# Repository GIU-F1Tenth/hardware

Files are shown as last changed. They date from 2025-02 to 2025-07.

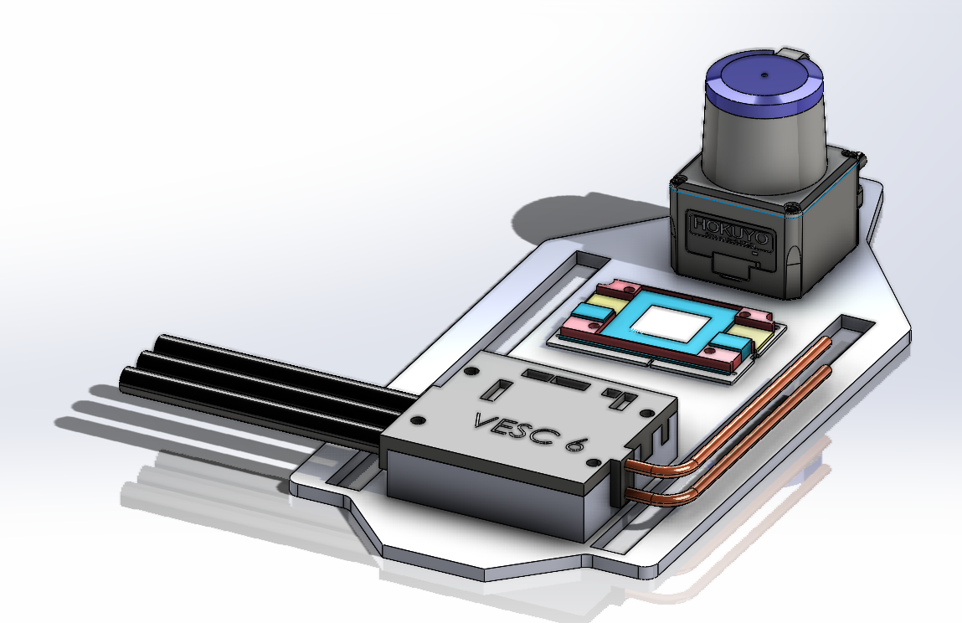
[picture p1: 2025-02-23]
Components3DModelling/Assm.png

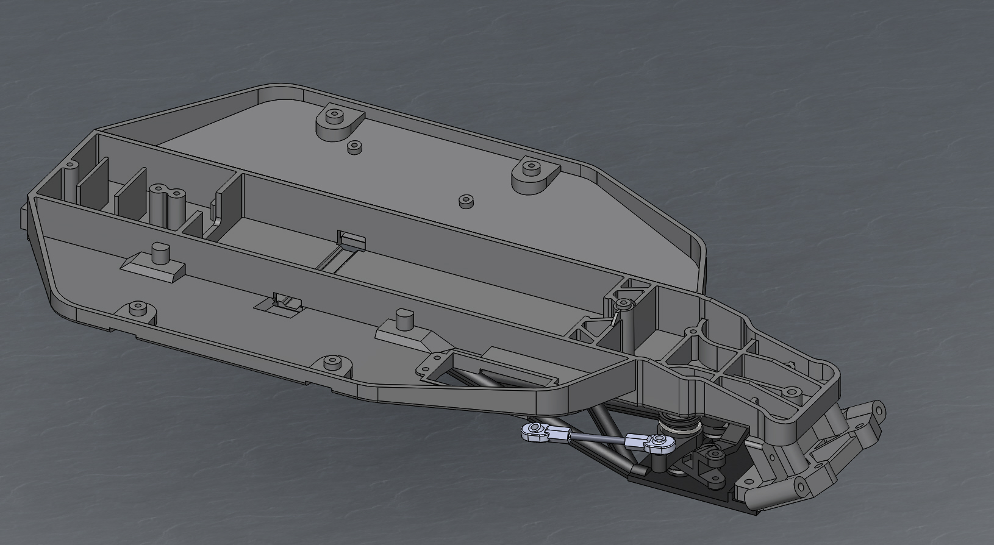
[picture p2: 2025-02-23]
Components3DModelling/Traxxas Car/TraxxasCarModel/Chassis.JPG

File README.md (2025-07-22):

# F1TENTH Hardware Repository

## Overview
Welcome to the F1TENTH Hardware Repository! This repository provides all the documentation, models, manuals, and resources needed to build, assemble, and test the F1TENTH hardware platform. Whether you're sourcing components, assembling parts, or troubleshooting, you'll find everything you need here.

## Repository Structure

- [**BOM/**](BOM/): Bills of Materials for hardware builds, including part numbers, quantities, and suppliers.
- [**Components3DModelling/**](Components3DModelling/): 3D CAD models (STL, STEP, etc.) for all hardware components.
- [**Components_Instruction_manual/**](Components_Instruction_manual/): Assembly guides, user manuals, datasheets, and technical specifications for sensors, actuators, controllers, and more.
- [**Documentations/**](Documentations/): Hardware testing procedures, results, and troubleshooting guides.
- [**Architecture/**](Architecture/): System architecture diagrams and platform overviews.

## Getting Started

1. **Clone the repository:**
   ```sh
   git clone https://github.com/your-repo/f1tenth-hardware.git
   ```
2. **Explore the folders:**
   - For part lists and sourcing, see [BOM/](BOM/).
   - For 3D models, visit [Components3DModelling/](Components3DModelling/).
   - For assembly and technical info, check [Components_Instruction_manual/](Components_Instruction_manual/).
   - For testing and troubleshooting, use [Documentations/](Documentations/).
   - For system diagrams, see [Architecture/](Architecture/).

## Contributions

Contributions are welcome! By contributing, you agree that your submissions will be licensed under the terms of the MIT License. Please submit improvements, corrections, or new documentation via pull request or open an issue. All contributions should include clear documentation and follow standard open-source practices.

---
For questions or support, refer to the relevant folders or contact the maintainers.
Author : Mohammed Abdelazim(mohammed@azab.io)
Maintainer : Yousuf Aboeldahab(yousuf.moh.dahab@outlook.com)

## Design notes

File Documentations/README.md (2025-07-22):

# Documentations

## Overview
This folder contains hardware testing procedures, results, and troubleshooting guides for the F1TENTH platform.

## Folder Structure

- [**LiDARTesting.pdf**](LiDARTesting.pdf): Testing report for LiDAR sensors.
- [**LiPo.Battery.Charger.Testing.Report.pdf**](LiPo.Battery.Charger.Testing.Report.pdf): Battery charger testing documentation.
- [**VESCTesting.pdf**](VESCTesting.pdf): VESC controller testing report.

## Getting Started

1. Review the relevant PDF for your hardware component.
2. Use the documentation for setup, testing, and troubleshooting.

## Contributions

Contributions are welcome! By contributing, you agree that your submissions will be licensed under the terms of the MIT License. Please submit improvements, corrections, or new documentation via pull request or open an issue. All contributions should include clear documentation and follow standard open-source practices.

---
For questions or support, refer to the files in this folder or contact the maintainers.
Author : Mohammed Abdelazim (mohammed@azab.io)
Maintainer : Yousuf Aboeldahab (yousuf.moh.dahab@outlook.com)

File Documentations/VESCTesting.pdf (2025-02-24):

# VESC 6 MkVI Testing

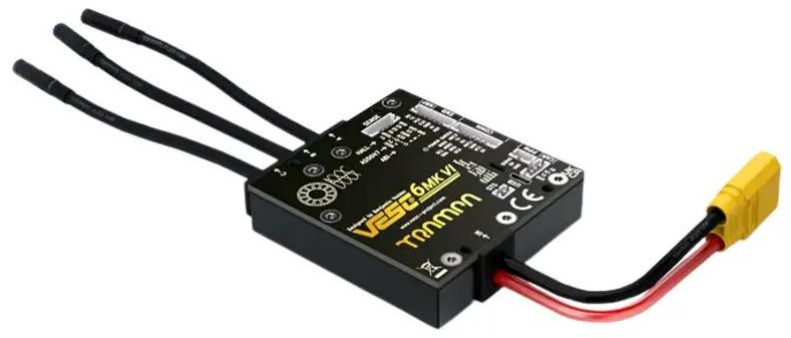
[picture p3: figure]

Author: Mohammed Azab
Date: 20 Feb 2025
Version: 1.0

Table of Contents

I. Introduction
II. | Prerequisites
III. | Software Setup
IV. | Motor Configuration
V. Battery Configuration
VI. | Running the Motor Test
VII. | Control Mode Testing
VIII. | Data Logging & Performance Analysis
IX. | Performance Testing
X. Troubleshooting
XI. | Safety Precautions
XII. | Conclusion
XIII. | References

### 1. Introduction

What is VESC?

VESC (Vedder Electronic Speed Controller) is an open-source ESC (Electronic Speed Controller) designed for brushless motors, offering extensive configurability, real-time monitoring, and customization via the VESC Tool software. Developed by Benjamin Vedder, VESC is widely used in electric skateboards, robotics, RC vehicles, and other high-performance motor applications.

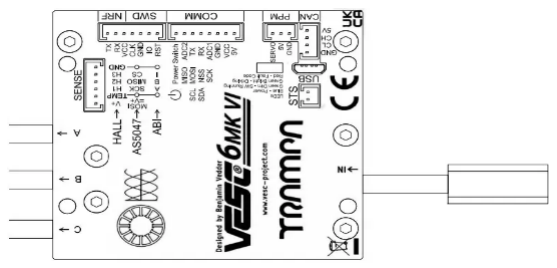
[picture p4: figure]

This document details the process of testing a VESC 6 MkVI using the VESC Tool, ensuring proper motor functionality, verifying sensor feedback, and optimizing performance for a Velineon 3500 motor paired with a 7200mAh high-performance LiPo battery.

### 2. Prerequisites

Hardware / Components Used:

- VESC Controller (VESC 6 MKVI)
- Brushless Motor: Velineon 3500 (Traxxas Ultimate Slash 4x4)
- Battery Pack (7200mAh 2S LiPo)
- Computer with VESC Tool installed
- USB-C Cable (for VESC connection)

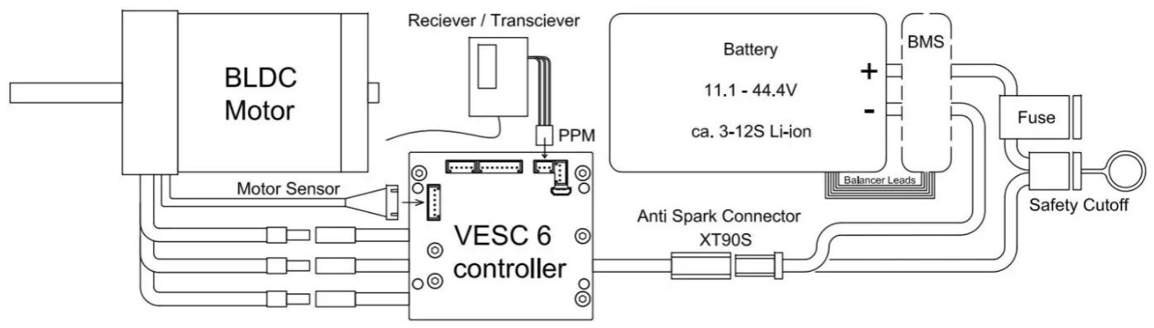
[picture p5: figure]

Software:

- VESC Tool (download from VESC Project) (https://vesc-project.com/)
- Latest VESC Firmware

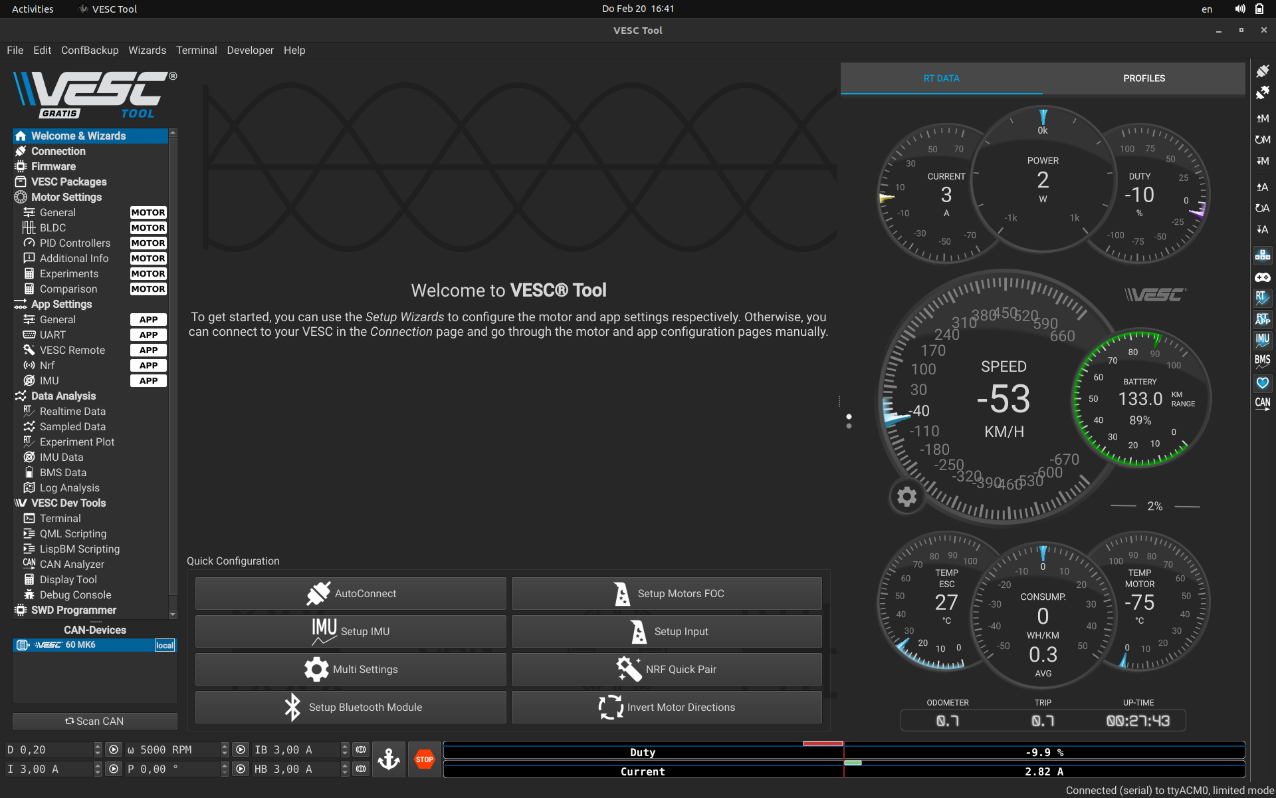
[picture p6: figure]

Wiring Connections:

1. Connect the motor phase wires to the VESC motor output.
2. Connect the battery to the VESC’s power input.
3. Use a power management circuit if additional safety is required.
4. Plug the USB cable into the VESC and connect it to the computer.
5. Ensure sensor wires (if using a sensored motor) are properly attached.

### 3. Software Setup

1. Download and install VESC Tool from the official website.
2. Open VESC Tool and connect the VESC via USB.
3. Power on the VESC and motor system.
4. Click on Auto Connect to establish communication with the VESC.

### 4. Motor Configuration

1. Navigate to Motor Setup Wizard.
2. Select motor type:
- Sensorless or Sensored BLDC for the Velineon 3500.
3. Run the detection process, where VESC Tool will:
- Identify motor resistance & inductance
- Calculate KV rating
- Measure motor flux linkage
4. Apply the detected values and save the configuration.

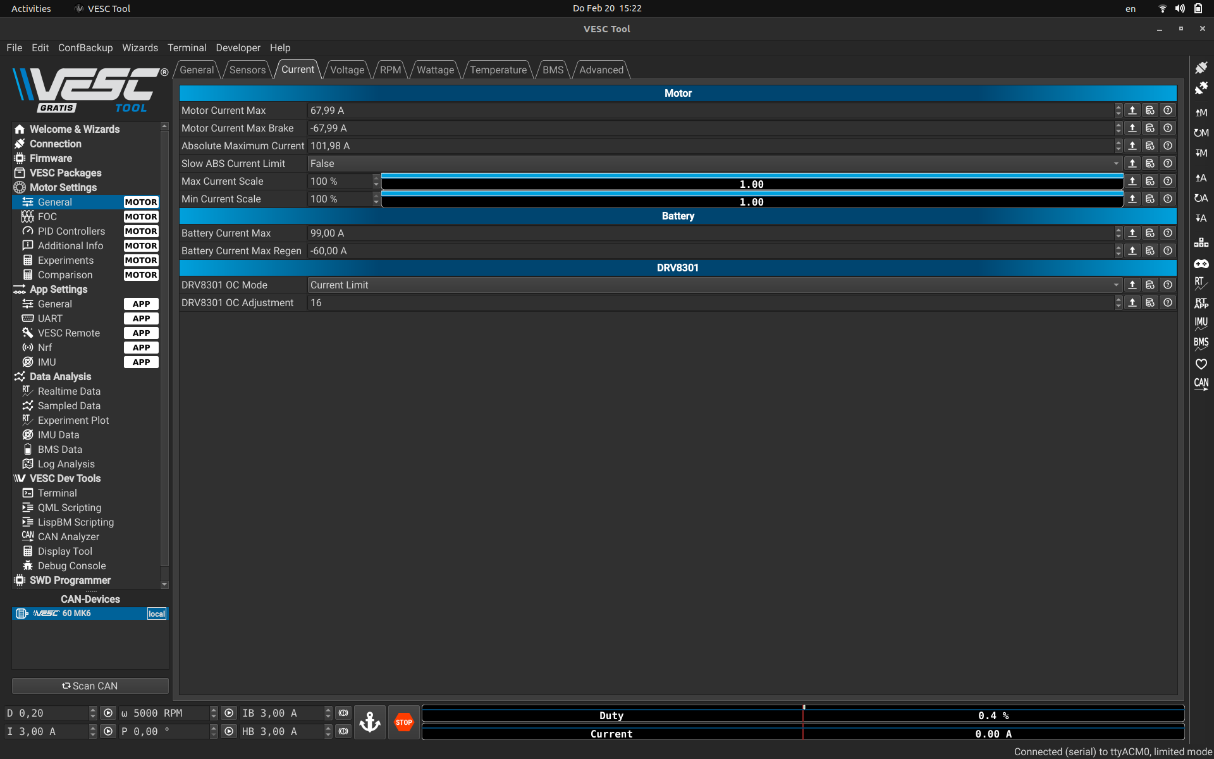
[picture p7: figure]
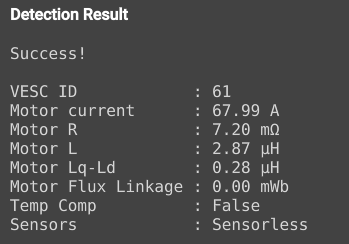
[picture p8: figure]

### 5. Battery Configuration

1. Go to Battery Settings.
2. Set:
- Battery Type: LiPo
- Capacity: 7200mAh
- Cell Count: 2S (7.4V)
- Voltage Cutoff Limits:
- Soft Cutoff: 3.4V per cell
- Hard Cutoff: 3.2V per cell
3. Save the configuration.

### 6. Running the Motor Test

1. Secure the motor in place to avoid movement.
2. Click Start Motor Testin the VESC Tool.
3. Observe RPM, current draw, and temperature.
4. Ensure the motor runs smoothly with no abnormal noises.
5. If issues arise, rerun motor detection or adjust parameters.

### 7. Control Mode Testing

1. Navigate to App Settings and select control mode:
- PPM (for Remote Control)
- UART (for external controllers)
- FOC Open Loop (for debugging)
2. Test throttle response via Realtime Data tab.
3. Adjust settings if necessary.

### 8. Data Logging & Performance Analysis

- Enable RT Data Logging to record real-time performance.
- Use Graphing Toolsin VESC Tool for analysis.
- Check Faultsif any error messages appear.
- Adjust motor/battery limits as needed for optimal performance.

### 9. Performance Testing

1. Use Realtime Data Monitoring to check:
- Motor RPM
- Current Draw
- Temperature
- Battery Voltage & Amps
2. Perform low-speed and high-speed tests under load.
3. Check for thermal throttling or overcurrent issues.
4. Adjust Current Limits, ERPM Limits, and Duty Cycle if needed.

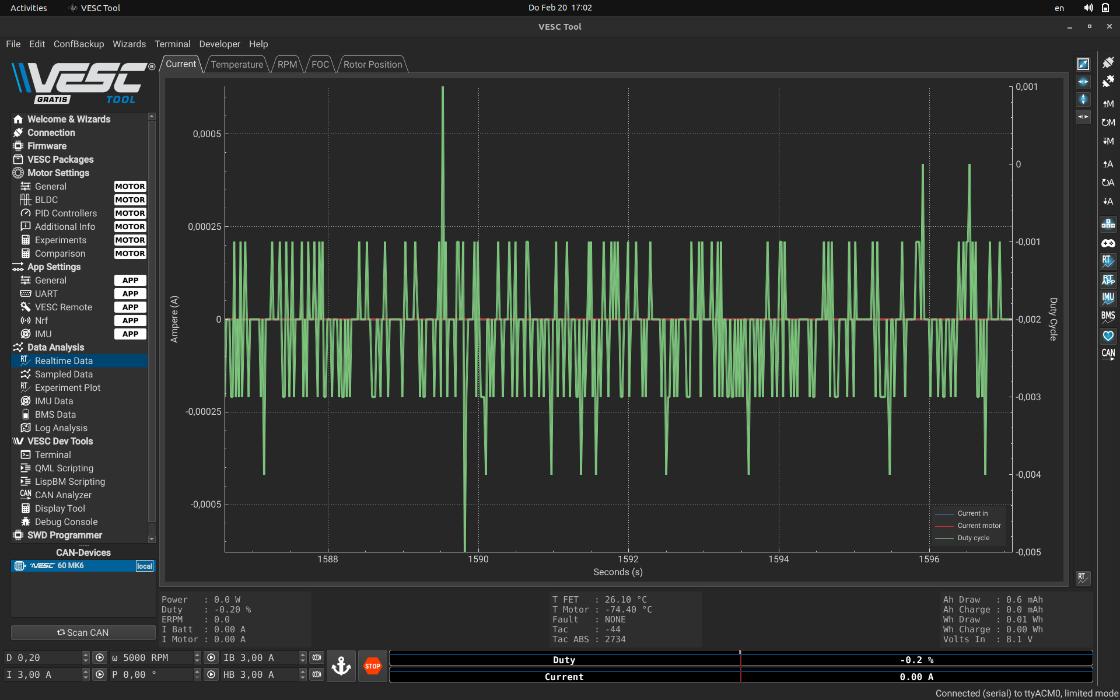
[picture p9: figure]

### 10. Troubleshooting

Issue | Possible Cause | Solution
No Motor Response | Loose connection | Check all wiring
Overcurrent Fault | High current settings | Reduce current limits
Overheating | Poor cooling | Ensure proper ventilation
Sudden Cutoffs | Battery voltage drop | Adjust voltage limits

### 11. Safety Precautions

- Always secure the motor before running tests.
- Avoid exceeding battery discharge limits.
- Regularly check VESC temperatures.
- Do not connect battery polarity in reverse.

### 12. Conclusion

After configuring and testing the VESC with the Velineon 3500 and 7200mAh LiPo battery, the motor performed as expected, with smooth acceleration and proper response. Further optimizations may be needed based on specific driving conditions.

Next Steps:

- Fine-tune PID settingsfor better efficiency.
- Experiment with FOC mode for quieter operation.
- Implement data logging for performance tracking.

### 13. References

- VESC Official Documentation (https://vesc-project.com/)
- Traxxas Velineon 3500 Specs (https://traxxas.com/)

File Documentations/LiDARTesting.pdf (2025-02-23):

# LiDAR Hokuyu UST-10LX Test Report

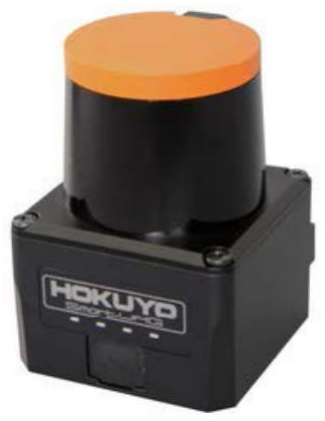
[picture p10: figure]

### Date: 10.Feb.2025

Version: 1.0

Reported by:

### Nada Mahmoud

### Mohammed Azab

### Farah Sayed

# Table of Contents

### 1. Objective

### 2. Equipment & Components

### 3. Testing Procedure

### - Figuring Out Connections

### - How to Connect to Ethernet with Hokuyu

### - URG Benri software

### - Connecting to Power

### 4. Test Results & Observations

### 5. Safety Guidelines & Best Practices

### 6. Conclusion & Recommendations

# 1. Objective

Our primary goal was to develop a method for simulating the Hokuyo LiDAR and evaluating its

functionality.

# 2. Equipment and Components

HOKUYU UST-10LX:

The smallest and the lightest of its kind.

It is possible to detect size, position and the moving direction of objects.

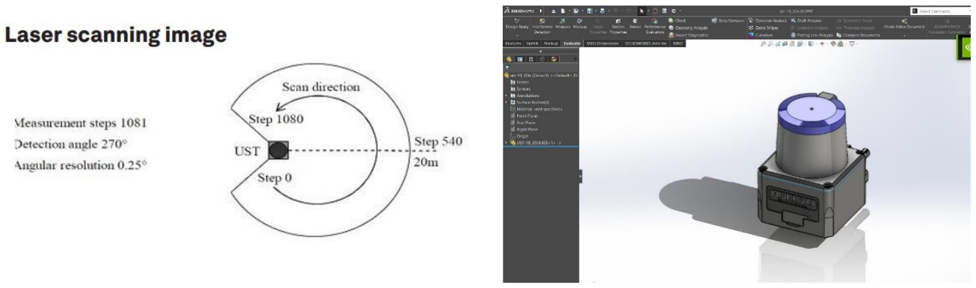
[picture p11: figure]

Mid-Detection Range | Up to 10m
Wide Detection Angle | 270 °
Fast Response | 25msec
High Angular Resolution | 0.25°
Supply Voltage | DC 12V / DC 24V (operation range 10 to 30 V ripple within 10%)
Supply Current | 150 mA or less (during start up 450 mA is necessary)
Accuracy | ± 40 mm *1Scan angle 270°

Scan Speed | 25 ms (motor speed 2,400 rpm)
Start-up Time | Within 10 sec (start-up time differs if malfunction is detected during start up)
Input | IP reset input, photo-coupler input (current 4 mA at ON)
Output | Synchronous output, photo coupler open collector output 30 VDC 50 mA MAX
Interface | Ethernet 100BASE-TX LED display
Power Supply | LED display (blue): Blinks during start up and malfunction state
Weight | 130 g (excluding cable)
Material | Front case: polycarbonate Rear case: aluminum
Dimensions | (W × D × H) 50 × 50 × 70 mm (sensor only)

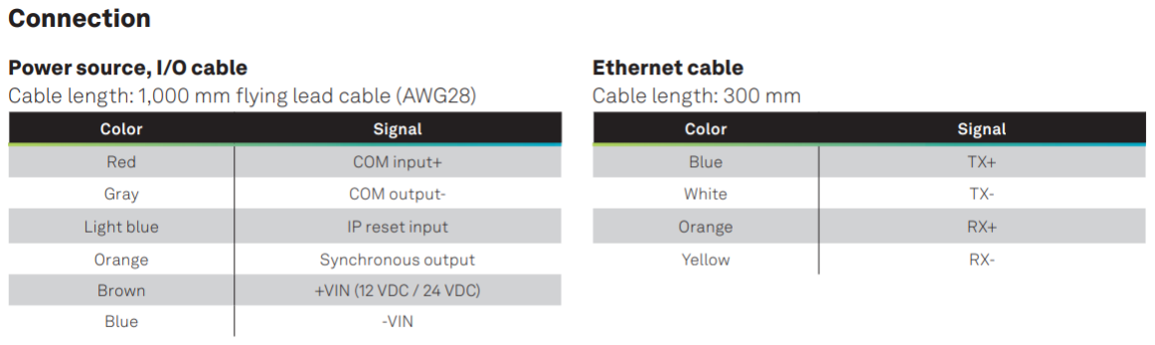
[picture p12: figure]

For more information, check out the Data/Specs Sheet:

- https://hokuyo-usa.com/application/files/6716/8451/4574/Hokuyo_-_UST-10LX_-

_Spec_Sheet_-_Final.pdf (https://hokuyo-usa.com/application/files/6716/8451/4574/Hokuyo_-_UST-10LX_-_Spec_Sheet_-_Final.pdf)

- https://autonomoustuff.com/-

/media/Images/Hexagon/Hexagon%20Core/autonomousstuff/pdf/hokuyo-ust-10lx-

datasheet.ashx?la=en&hash=95B57270899F50608C18BF48CC1AD043 (https://autonomoustuff.com/-/media/Images/Hexagon/Hexagon%20Core/autonomousstuff/pdf/hokuyo-ust-10lx-datasheet.ashx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)

# 3. Testing Procedure

### 3.1. Figuring Out Connections

We began by referencing the data and specifications sheet to identify the

correct wire connections for data compatibility. After analyzing the wiring

configuration, we realized we did not have the proper connection. So, we

soldered a connection using a resistor wire and connecting wire. We

connected the blue wire to -Vin and the brown wire to +Vin.

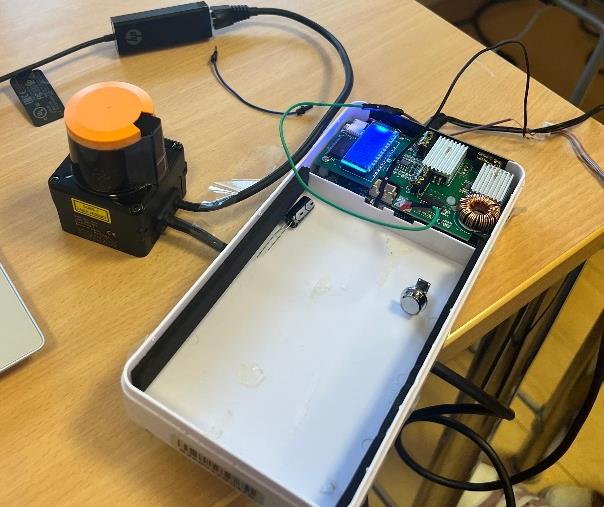
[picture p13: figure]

### 3.2. How to Connect to Ethernet with Hokuyu

To connect the Hokuyo LiDAR via Ethernet, we configured the PC’s network

settings to match the LiDAR’s IP address range, ensuring proper

communication before performing a ping test to verify connectivity.

### 3.3. URG Benri Software

URG Benri is a software tool developed by Hokuyo for configuring, testing,

and visualizing data from their LiDAR sensors. It allows users to adjust sensor

settings, visualize real-time data, log scan results, and perform diagnostic

tests. It allowed us to test the LiDAR through a graphical interface. It can be

downloaded and installed from Hokuyo’s official website. After installing it, we connected it to the LiDAR, configured network settings, and connected it

to power to verify functionality.

### 3.4. Connecting to Power

Initially, we attempted to connect the LiDAR to an Arduino that provided

only 5V, which was insufficient since the LiDAR requires a minimum input

of 10V. As a result, we switched to using the power bank included with the

TRAXXAS kit, which supplied 12V to the LiDAR, making it functional.

# 4. Test Results and Observation

The URG Benri software visualizes the data collected by the Hokuyu and displays green

when the path is clear. If an object is placed within a 10-meter radius, the green light is

blocked.

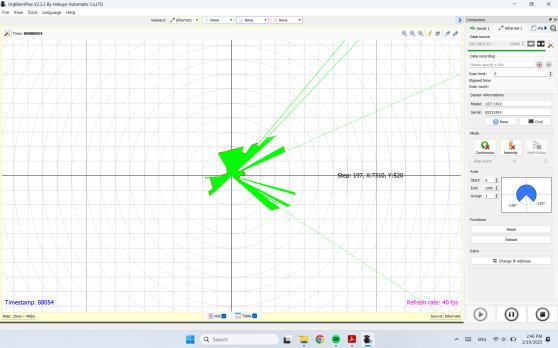
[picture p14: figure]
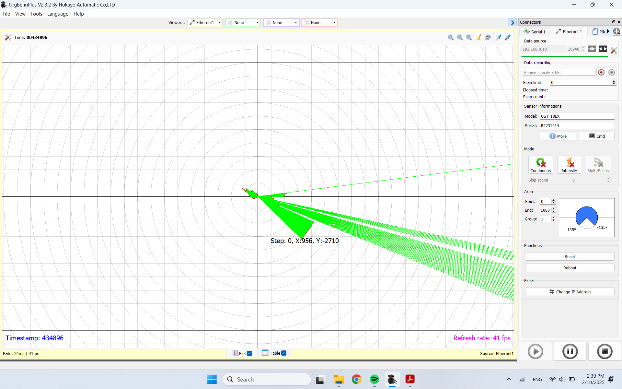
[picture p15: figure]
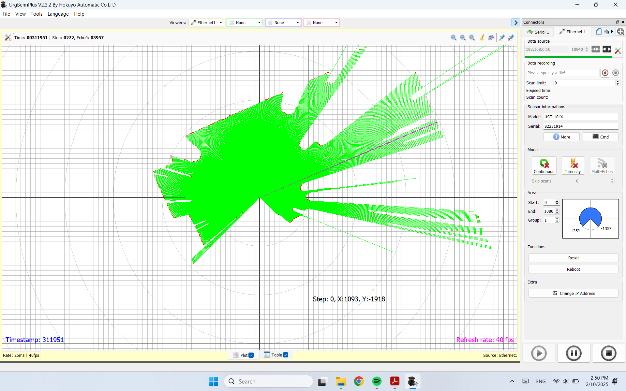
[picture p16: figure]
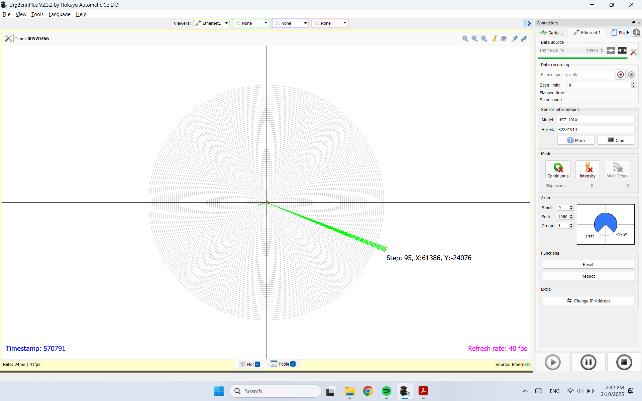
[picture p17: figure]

# 5. Safety Guidelines

- Operate the LiDAR in a clean environment with normal temperatures, away from

dust and moisture.

- Regularly clean the lens with care. This component is crucial for our object detection

system, which will rely heavily on it, and it is also of significant cost, so it must be

handled with caution.

# 6. Conclusion and Recommendations

We successfully tested the LiDAR, and its performance met our expectations. However,

there are still some very slight uncertainties regarding its accuracy, as well as whether an

additional component, such as a camera, will be needed for object detection. It is crucial to

handle the device with great care. Further testing is required, particularly once all

components are integrated and the car is prepared to begin autonomously moving.

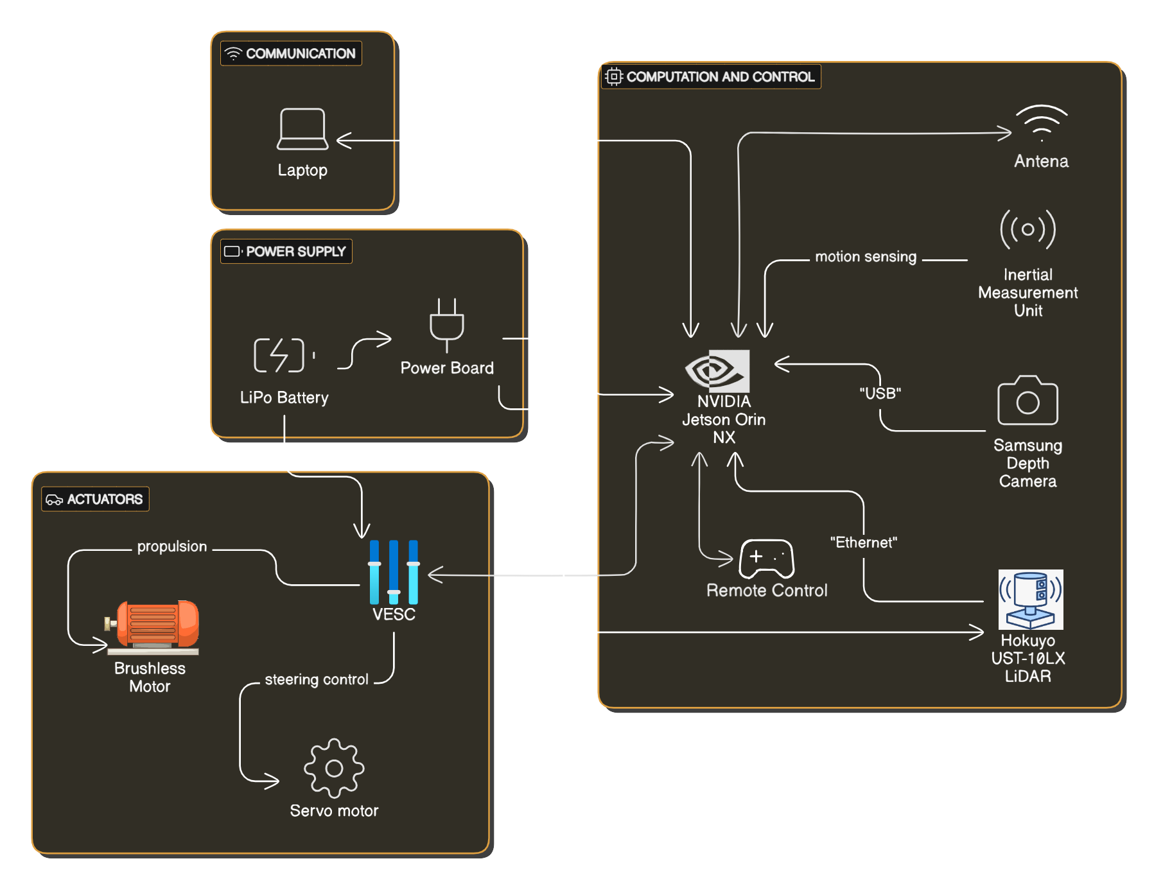
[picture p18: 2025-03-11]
Architecture/F1TenthHardwareArchitecture.png

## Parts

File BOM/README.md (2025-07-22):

# BOM

## Overview
This folder contains Bills of Materials for hardware builds, including part numbers, quantities, and suppliers for the F1TENTH platform.

## Folder Structure

- [**F1TenthBOM2025.xlsx**](F1TenthBOM2025.xlsx): Bill of materials for the 2025 build.
- [**Roboracer2026BOM.xlsx**](Roboracer2026BOM.xlsx): Bill of materials for the 2026 build.

## Getting Started

1. Open the relevant Excel file for your build year.
2. Use the listed part numbers and suppliers to source components.

## Contributions

Contributions are welcome! By contributing, you agree that your submissions will be licensed under the terms of the MIT License. Please submit improvements, corrections, or new documentation via pull request or open an issue. All contributions should include clear documentation and follow standard open-source practices.

---
For questions or support, refer to the files in this folder or contact the maintainers.
Author : Mohammed Abdelazim (mohammed@azab.io)
Maintainer : Yousuf Aboeldahab (yousuf.moh.dahab@outlook.com)

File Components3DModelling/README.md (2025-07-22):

# Components3DModelling

## Overview
This folder contains all 3D CAD models and related files for the hardware components of the F1TENTH platform. These resources support manufacturing, 3D printing, and assembly of the vehicle and its accessories.

## Folder Structure

- [**PlatformDeck/**](PlatformDeck/): Main deck assemblies, part files, and reference images (see PlatformDeck/README.md for details).
- [**AntennaMount/**](AntennaMount/): CAD files and gcode for antenna mounts.
- [**Battery Holder/**](Battery%20Holder/): 3D models for battery holders and mounting solutions.
- [**Jetson/**](Jetson/): CAD resources for Jetson modules and accessories.
- [**Lidar/**](Lidar/): 3D models and drawings for LiDAR mounting and integration.
- [**RearWing/**](RearWing/): Files for rear wing components and mounts.
- [**Traxxas Car/**](Traxxas%20Car/): CAD files for Traxxas car integration and modifications.
- [**Vesc/**](Vesc/): Models and images for VESC controller mounting and wiring.
- **Assm.png**: Reference image for overall assembly.

## Getting Started

1. Browse subfolders for specific component models and assemblies.
2. Use .STL, .STEP, .IGS, and .dxf files for 3D printing or manufacturing.
3. Refer to images and README files in subfolders for assembly guidance.

## Contributions

Contributions are welcome! By contributing, you agree that your submissions will be licensed under the terms of the MIT License. Please submit improvements, corrections, or new documentation via pull request or open an issue. All contributions should include clear documentation and follow standard open-source practices.

---
For questions or support, refer to the files in this folder or contact the maintainers.
Author : Mohammed Abdelazim (mohammed@azab.io)
Maintainer : Yousuf Aboeldahab (yousuf.moh.dahab@outlook.com)

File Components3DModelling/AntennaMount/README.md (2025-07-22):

# AntennaMount

## Overview
This folder contains CAD models and gcode files for antenna mounts used in the F1TENTH hardware platform.

## Folder Structure
- **AntennaMount_0.15mm_PLA_MK3S_1h5m.gcode**: G-code file for 3D printing the mount.

## Getting Started

1. Use the .STL file for 3D printing the antenna mount.
2. Refer to the .SLDPRT file for editing or customizing the design.
3. Use the provided gcode for direct printing on compatible printers.

## Contributions

# AntennaMount

## Overview
This folder contains CAD models and gcode files for antenna mounts used in the F1TENTH hardware platform.

## Folder Structure

- [**AntennaMount.SLDPRT**](AntennaMount.SLDPRT): SolidWorks part file for the antenna mount.
- [**AntennaMount.STL**](AntennaMount.STL): 3D printable model of the antenna mount.
- [**AntennaMount_0.15mm_PLA_MK3S_1h5m.gcode**](AntennaMount_0.15mm_PLA_MK3S_1h5m.gcode): G-code file for 3D printing the mount.

## Getting Started

1. Use the .STL file for 3D printing the antenna mount.
2. Refer to the .SLDPRT file for editing or customizing the design.
3. Use the provided gcode for direct printing on compatible printers.

## Contributions

Contributions are welcome! By contributing, you agree that your submissions will be licensed under the terms of the MIT License. Please submit improvements, corrections, or new documentation via pull request or open an issue. All contributions should include clear documentation and follow standard open-source practices.

---
For questions or support, refer to the files in this folder or contact the maintainers.
Author : Mohammed Abdelazim (mohammed@azab.io)
Maintainer : Yousuf Aboeldahab (yousuf.moh.dahab@outlook.com)

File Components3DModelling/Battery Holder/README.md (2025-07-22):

# Battery Holder

## Overview
This folder contains 3D models and files for battery holders and mounting solutions for the F1TENTH platform.

## Folder Structure

- [**Traxxas 4x4 LCG XL battery hold down.3mf**](Traxxas%204x4%20LCG%20XL%20battery%20hold%20down.3mf): 3D model for battery hold down.

## Getting Started

1. Use the .3mf file for 3D printing the battery holder.
2. Modify the file as needed for your battery configuration.

## Contributions

Contributions are welcome! By contributing, you agree that your submissions will be licensed under the terms of the MIT License. Please submit improvements, corrections, or new documentation via pull request or open an issue. All contributions should include clear documentation and follow standard open-source practices.

---
For questions or support, refer to the files in this folder or contact the maintainers.
Author : Mohammed Abdelazim (mohammed@azab.io)
Maintainer : Yousuf Aboeldahab (yousuf.moh.dahab@outlook.com)

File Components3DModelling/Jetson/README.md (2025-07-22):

# Jetson

## Overview
This folder contains CAD models and resources for NVIDIA Jetson modules and accessories used in the F1TENTH platform.

## Folder Structure

- [**Jetson_Orin_NX_Orin_Nano_Module_3D_STEP_Model_20230310/**](Jetson_Orin_NX_Orin_Nano_Module_3D_STEP_Model_20230310/): STEP models for Jetson Orin NX and Nano modules.

## Getting Started

1. Use the STEP models for integration and mounting of Jetson modules.
2. Refer to subfolder documentation for details.

## Contributions

Contributions are welcome! By contributing, you agree that your submissions will be licensed under the terms of the MIT License. Please submit improvements, corrections, or new documentation via pull request or open an issue. All contributions should include clear documentation and follow standard open-source practices.

---
For questions or support, refer to the files in this folder or contact the maintainers.
Author : Mohammed Abdelazim (mohammed@azab.io)
Maintainer : Yousuf Aboeldahab (yousuf.moh.dahab@outlook.com)

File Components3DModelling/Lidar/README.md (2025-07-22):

# Lidar
# Lidar

## Overview
This folder contains 3D models and drawings for LiDAR mounting and integration on the F1TENTH platform.

## Folder Structure

- [**UST-10_20LX.IGS**](UST-10_20LX.IGS): 3D model for LiDAR sensor.
- [**ust-10_20lx.SLDPRT**](ust-10_20lx.SLDPRT): SolidWorks part file for LiDAR component.

## Getting Started

1. Use the .IGS and .SLDPRT files for mounting and integration of LiDAR sensors.
2. Modify the files as needed for your specific LiDAR model.

## Contributions

Contributions are welcome! By contributing, you agree that your submissions will be licensed under the terms of the MIT License. Please submit improvements, corrections, or new documentation via pull request or open an issue. All contributions should include clear documentation and follow standard open-source practices.

---
For questions or support, refer to the files in this folder or contact the maintainers.
Author : Mohammed Abdelazim (mohammed@azab.io)
Maintainer : Yousuf Aboeldahab (yousuf.moh.dahab@outlook.com)

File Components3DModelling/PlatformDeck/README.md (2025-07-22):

# PlatformDeck

## Overview
The PlatformDeck folder contains all files and resources related to the main deck of the F1TENTH hardware platform. This includes 3D CAD models, assembly files, and reference images for building and customizing the platform deck.

## Folder Structure

- [**FullAssemblyAttempt.SLDASM**](FullAssemblyAttempt.SLDASM), [**FullAssemblyDetachedComponents.SLDASM**](FullAssemblyDetachedComponents.SLDASM), [**AssembledPlatform.SLDASM**](AssembledPlatform.SLDASM): SolidWorks assembly files for different deck configurations.
- [**PlatformAs1Part.SLDPRT**](PlatformAs1Part.SLDPRT), [**PlatformFrontFinal.SLDPRT**](PlatformFrontFinal.SLDPRT), [**PlatformRearFinal.SLDPRT**](PlatformRearFinal.SLDPRT), [**thePeg.SLDPRT**](thePeg.SLDPRT): SolidWorks part files for individual deck components and accessories.
- [**PlatformAs1Part.STL**](PlatformAs1Part.STL), [**PlatformFrontFinal.STL**](PlatformFrontFinal.STL), [**PlatformRearFinal.STL**](PlatformRearFinal.STL), [**thePeg.STL**](thePeg.STL): Exported 3D models for 3D printing.
- [**PlatformAs1Part.dxf**](PlatformAs1Part.dxf), [**UST-10_20LX.IGS**](UST-10_20LX.IGS): Drawings and models for manufacturing or reference.
- [**photosidentifer.png**](photosidentifer.png): Reference images showing assembled decks and component placements.
- [**PlatformCadFiles/**](PlatformCadFiles/): Additional CAD files and resources for deck customization.

## Getting Started

1. Browse the available assembly files (.SLDASM) to view different deck configurations.
2. Use the part files (.SLDPRT) and exported models (.STL, .IGS, .dxf) for manufacturing or 3D printing.
3. Refer to the images for guidance on assembly and component placement.
4. For further customization, explore the PlatformCadFiles subfolder.

## Contributions

Contributions are welcome! By contributing, you agree that your submissions will be licensed under the terms of the MIT License. Please submit improvements, corrections, or new documentation via pull request or open an issue. All contributions should include clear documentation and follow standard open-source practices.

---
For questions or support, refer to the files in this folder or contact the maintainers.
Author : Mohammed Abdelazim (mohammed@azab.io)
Maintainer : Yousuf Aboeldahab (yousuf.moh.dahab@outlook.com)

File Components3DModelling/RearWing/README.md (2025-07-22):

# RearWing

## Overview
This folder contains CAD models and files for rear wing components and mounts for the F1TENTH platform.

## Folder Structure

- Rear wing part and assembly files (see folder for details).

## Getting Started

1. Browse the files for rear wing models and mounting solutions.
2. Use the provided CAD files for 3D printing or manufacturing.

## Contributions

Contributions are welcome! By contributing, you agree that your submissions will be licensed under the terms of the MIT License. Please submit improvements, corrections, or new documentation via pull request or open an issue. All contributions should include clear documentation and follow standard open-source practices.

---
For questions or support, refer to the files in this folder or contact the maintainers.
Author : Mohammed Abdelazim (mohammed@azab.io)
Maintainer : Yousuf Aboeldahab (yousuf.moh.dahab@outlook.com)

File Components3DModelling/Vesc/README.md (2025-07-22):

# Vesc

## Overview
This folder contains models and images for VESC controller mounting and wiring for the F1TENTH platform.

## Folder Structure

- VESC controller part files, images, and wiring diagrams (see folder for details).

## Getting Started

1. Browse the files for VESC controller models and mounting solutions.
2. Use the provided files for integration and wiring reference.

## Contributions

Contributions are welcome! By contributing, you agree that your submissions will be licensed under the terms of the MIT License. Please submit improvements, corrections, or new documentation via pull request or open an issue. All contributions should include clear documentation and follow standard open-source practices.

---
For questions or support, refer to the files in this folder or contact the maintainers.
Author : Mohammed Abdelazim (mohammed@azab.io)
Maintainer : Yousuf Aboeldahab (yousuf.moh.dahab@outlook.com)

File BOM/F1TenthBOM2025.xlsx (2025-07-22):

Number | Name | Amount | Unit Price | Total Price | Justification | Links
1 | IMU Sparkfun OpenLog Artemis 16832 | 1 | €50.94 | €50.94 | The IMU we received from Korea was not functional, we bought the newer version since the older one was discontiued | https://www.digikey.de/de/products/detail/sparkfun-electronics/DEV-16832/13166206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
2 | LiPo Battery 2s 7.4V 7200mAh | 1 | €33.99 | €33.99 | We need an extra battery in case the one we already have ran out in the middle of the race | https://www.amazon.de/-/en/Battery-80C-Deans-Truck-Truggy/dp/B07NSTY7SN
3 | Battery Charger | 1 | €38.99 | €38.99 | We need a charger for the batteries | https://www.amazon.de/-/en/Charger-Balancer-Balance-Li-Ion-Supply-blue/dp/B08NJXYKGL
4 | Suspension | 1 | €22.96 | €22.96 | The suspension we already have is missing springs and isnt 100% functional | https://www.amazon.de/-/en/Traxxas-Absorber-Rustler-Stampede-Upgrades/dp/B0BD7N1D3N?nsdOptOutParam=true
5 | Traxxas Receiver | 1 | €45.25 | €45.25 | The receiver we have is not functional and we need it to implement the dead-man switch | https://www.amazon.de/-/en/gp/product/B00WOZCX7M/ref=ox_sc_act_title_1?smid=A3OPR8B412VPSF&psc=1
6 | Lidar Hokuyo UST-10LX | 1 | €1725.50 | €1725.50 | We chose this lidar because it has the best specifications that are within F1Tenth regulations | https://eu.robotshop.com/de/products/hokuyo-ust-10lx-scan-laser-entfernungsmesser?gad_source=1
7 | NVIDIA Jetson Orin NX 16GB | 1 | €994.50 | €994.50 | We chose this Jetson because it works the best with our requirements for the machine learning algorithms | https://www.reichelt.de/de/en/nvidia-jetson-orin-nx-bundle-8x-2-ghz-16-gb-ddr5-jetson-orin-4012-p350587.html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
8 | Antennas | 1 | €6.99 | €6.99 | For the Jetson | https://www.amazon.de/Connector-Wireless-Security-Surveillance-Bluetooth-2pcs-Black/dp/B08YMYZGG1
9 | Controller | 1 | €41.90 | €41.90 | To control car and deadman switch | https://www.amazon.de/-/en/Logitech-wireless-controller-Konsolenartigem-buttons/dp/B00CJ5FP2C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
10 | Safety Bag for Battery | 1 | €10.99 | €10.99 | Safety bag for LiPo batteries | https://www.amazon.de/-/en/Fireproof-Waterproof-Container-Explosion-proof-Explosion/dp/B0D1KK14M9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
11 | VESC 6 MkVI | 1 | €230.10 | €230.10 | Motor Controller since the one we already have will not be sufficient | https://trampaboards.com/vesc-6-mkvi--trampa-gives-you-maximum-power-p-34848.html
12 | Power Board | 1 | €30.00 | €30.00 | To distribute Power | https://oshpark.com/shared_projects/qvIKu3aY
13 | 560 Ohm Resistors | 1 | €5.69 | €5.69 | for powerboard (1 pack has 50 pieces) | https://www.amazon.de/-/en/Innfeeltech-Tolerance-Resistor-Project-Experiments/dp/B0CL6MT6TP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
14 | 0.33uF capacitors | 1 | €6.99 | €6.99 | for powerboard (1 pack has 20 pieces) | https://www.amazon.de/-/en/BOJACK-0-33uF-Capacitor-Metalized-Polypropylene/dp/B094ZQP2S8
15 | 0.1uF capacitors | 1 | €4.09 | €4.09 | for powerboard (1 pack has 100 pieces) | https://www.amazon.de/Generic-Stück-100nF-0-1uF-Keramikkondensator/dp/B01LWWKAIB
16 | 100uF capacitors | 1 | €3.59 | €3.59 | for powerboard (1 pack has 10 pieces) | https://www.amazon.de/-/en/ELKO-Electrolytic-Capacitor-100UF-Pack/dp/B00LSJ0R2I?nsdOptOutParam=true
17 | 10uF capacitors | 1 | €5.99 | €5.99 | for powerboard (1 pack has 50 pieces) | https://www.amazon.de/-/en/Innfeeltech-Electrolytic-Capacitors-Aluminium-Radial/dp/B0CPDG9K3W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
18 | 12V to 8V LDO | 1 | €7.99 | €7.99 | for powerboard (1 piece) | https://www.amazon.de/Hocheffizienter-LDO-Regler-Abwärtswandler-Wandler-Dropout/dp/B0C7FKJKTP?th=1
19 | 2 pin terminal | 10 | €0.84 | €8.36 | for powerboard (1 pack has 10 pieces) | https://www.mouser.de/ProductDetail/Phoenix-Contact/1729128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
20 | toggle switch | 1 | €6.91 | €6.91 | for powerboard (1 piece) | https://www.digikey.com/en/products/detail/nkk-switches/MN11S2A1W01/20838938
21 | 4 pin connector | 10 | €0.86 | €8.58 | for powerboard (1 pack has 10 pieces) | https://www.digikey.com/product-detail/en/B4B-XH-A(LF)(SN)/455-2249-ND/1651047/?itemSeq=302805122
22 | Power LED 5mm | 1 | €5.99 | €5.99 | for powerboard (1 piece) | https://www.reichelt.de/de/en/shop/product/led_5_mm_wired_cold_white_8700_mcd_140_-190382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
23 | 12V transformer | 1 | €38.95 | €38.95 | for powerboard (1 piece) | https://www.digikey.com/en/products/detail/PDQ30-Q24-S12-D/102-3892-ND/6165425?itemSeq=302805124
24 | DM Stickers | 1 | €37.10 | €37.10
25 | Boost Converter and Lipo Connector | 1 | €19.98 | €19.98
26 | Pin Connecors | 1 | €8.99 | €8.99
27 | Step Down Converters | 1 | €10.79 | €10.79
28 | DP Adaptors | 1 | €11.88 | €11.88
29 | Step Up Boost Converters | 1 | €7.99 | €7.99
30 | Batteries | 1 | €205.98 | €205.98
31 | Screws | 1 | €12.00 | €12.00
32 | PPM Connectors | 1 | €4.00 | €4.00
33 | KabelBlinder | 1 | €13.00 | €13.00
34 | Boost Convertor and Rastclip | 1 | €24.40 | €24.40
 |  |  | Total: | €3691.35

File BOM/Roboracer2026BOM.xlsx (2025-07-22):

Items | Qty | Cost per Unit | Total Cost | Comments | Link
Traxxas Fiesta ST Rally VXL Edition; 1/10 Scale Brushless Pro 4WD | 2 | €455.00 | €910.00 | comes with front foam bumper | https://www.monsterhopups.de/Traxxas-TRX74276-4-Ford-Fiesta-ST-Rally-VXL-RTR-110-Gruen
NVIDIA Jetson Orin NX 16GB | 2 | €994.50 | €1989.00 | we got the 8gb one last time, now we are opting for the 16gb | https://www.amazon.de/Yahboom-Orin-Kit-16GB-Basic-NX/dp/B0C77S9HFJ?mcid=94b184e3ef0d34c3a0656c01a007b5c6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
Traxxas Velineon 3500 Brushless Motor | 1 | €94.95 | €94.95 | extra motor | https://www.trashop.eu/traxxas-velineon-3500-brushless-motor-trx3351r.html
VESC 6 MkVI | 2 | €230.10 | €460.20 |  | https://trampaboards.com/vesc-6-mkvi--trampa-gives-you-maximum-power-p-34848.html
Camera D435 | 1 | €323.00 | €323.00 | camera for object detection | Intel RealSense Depth Camera D435: Amazon.de: Computer & Zubehör (https://www.amazon.de/Intel-RealSense-82635AWGDVKPRQ-Erfassung-beweglicher/dp/B07BLS5477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)
Lidar Hokuyo UST-10LX | 2 | €1725.50 | €3451.00 |  | https://eu.robotshop.com/de/products/hokuyo-ust-10lx-scan-laser-entfernungsmesser?gad_source=1
Battery Charger | 1 | €38.99 | €38.99 |  | https://www.amazon.de/-/en/Charger-Balancer-Balance-Li-Ion-Supply-blue/dp/B08NJXYKGL
PLA Filament 16 | 1 | €69.00 | €69.00 | for 3D printing | https://www.amazon.de/-/en/SUNLU-Filament-Multicolour-Printer-Individually/dp/B0DSZYHHRV
Safety Bag for Battery | 4 | €10.99 | €43.96 |  | https://www.amazon.de/-/en/Fireproof-Waterproof-Container-Explosion-proof-Explosion/dp/B0D1KK14M9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
IMU Sparkfun OpenLog Artemis 16832 | 1 | €50.94 | €50.94 |  | https://www.digikey.de/de/products/detail/sparkfun-electronics/DEV-16832/13166206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
LiPo Battery 4s | 2 | €102.99 | €205.98 |  | https://amzn.eu/d/cYab9pT
Step Down Converter | 2 | €8.45 | €16.90 |  | https://amzn.eu/d/icGjoV6
Boost Converter | 2 | €10.99 | €21.98 |  | https://amzn.eu/d/arX3nIb
WIFI Stick for PC | 3 | €18.00 | €54.00 | amazon has voucher for it 40 % | https://www.amazon.de/WONLINK-AX1800-Adapter-Desktop-Laptop-black/dp/B0F3HGH2XP?sp_csd=d2lkZ2V0TmFtZT1zcF9hdGY
VESC 6 PPM Cable | 4 | €4.49 | €17.96 |  | https://shop.electric-skateboard.net/diy-tuning/wires-and-connectors/747/vesc-6-ppm-cable
Bullet Adapter 4mm Male 3.5mm Female | 2 | €10.00 | €20.00 |  | https://www.amazon.de/-/en/3-5mm-Bullet-Connector-Connectors-Adapter/dp/B0BFHWWKX6?s=toys
XT90 Socket Female | 2 | €5.89 | €11.78 |  | https://www.amazon.de/-/en/Premium-Adapter-Current-Connector-Battery/dp/B078KN86G3
Controllerv1 | 1 | €39.00 | €39.00 | different controller | https://www.amazon.de/-/en/EasySMX-X15-Controller-Bluetooth-Compatible/dp/B0CSP1YQHN?s=ce-de
Controllerv2 | 1 | €42.00 | €42.00 |  | https://www.amazon.de/-/en/Logitech-wireless-controller-Konsolenartigem-buttons/dp/B00CJ5FP2C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
Fueran Dummy Plug Headless Ghost | 1 | €13.80 | €13.80 |  | https://www.amazon.de/Headless-Display-Emulator-Aluminium-Compatible-8K-1P/dp/B07D5G96D8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
Stücke XT90 Stecker auf TRX Buchse | 1 | €13.50 | €13.50 |  | https://www.amazon.de/St%C3%BCcke-Stecker-Buchse-Kabel-Ladeger%C3%A4t/dp/B07XQLVGYH
Suspension | 2 | €56.00 | €112.00 |  | suspensions (https://www.modellbau-berlinski.de/rc-fahrzeuge-und-zubehoer/autos-und-zubehoer/ersatz--und-tuningteile/traxxas/bandit/big-bore-daempfer-slash-rustler-stamped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)
Antennas | 2 | €6.00 | €12.00 |  | https://www.amazon.de/Connector-Wireless-Security-Surveillance-Bluetooth-2pcs-Black/dp/B09KTMZX5K
Traxxas id charge lead adapter | 2 | €11.80 | €23.60 |  | https://www.rcteam.com/en/products/beez2b-charging-cable-xt60-to-traxxas-id-4s-beec1056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
RC Car Work Stand Aluminium Repair | 1 | €13.99 | €13.99 |  | https://www.amazon.de/-/en/Aluminium-Workstation-Traxxas-Crawler-Monster/dp/B08GJHFDT4
ShareGoo Front Foam Bumper | 1 | €8.99 | €8.99 |  | https://www.amazon.com/dp/B07VFWKFZH?sp_csd=d2lkZ2V0TmFtZT1zcF9ocXBfc2hhcmVk
Power Board | 2 | €30.00 | €60.00 |  | https://oshpark.com/shared_projects/qvIKu3aY
560 Ohm Resistors | 1 | €5.69 | €5.69 |  | https://www.amazon.de/-/en/Innfeeltech-Tolerance-Resistor-Project-Experiments/dp/B0CL6MT6TP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
0.33uF capacitors | 1 | €6.99 | €6.99 |  | https://www.amazon.de/-/en/BOJACK-0-33uF-Capacitor-Metalized-Polypropylene/dp/B094ZQP2S8
0.1uF capacitors | 1 | €4.09 | €4.09 |  | https://www.amazon.de/Generic-St%C3%BCck-100nF-0-1uF-Keramikkondensator/dp/B01LWWKAIB
100uF capacitors | 1 | €3.59 | €3.59 |  | https://www.amazon.de/-/en/ELKO-Electrolytic-Capacitor-100UF-Pack/dp/B00LSJ0R2I?nsdOptOutParam=true
10uF capacitors | 1 | €5.99 | €5.99 |  | https://www.amazon.de/-/en/Innfeeltech-Electrolytic-Capacitors-Aluminium-Radial/dp/B0CPDG9K3W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
12V to 8V LDO | 2 | €7.99 | €15.98 |  | https://www.amazon.de/Hocheffizienter-LDO-Regler-Abw%C3%A4rtswandler-Wandler-Dropout/dp/B0C7FKJKTP
2 pin terminal | 10 | €0.84 | €8.36 |  | https://www.mouser.de/ProductDetail/Phoenix-Contact/1729128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
toggle switch | 2 | €6.91 | €13.82 |  | https://www.digikey.com/en/products/detail/nkk-switches/MN11S2A1W01/20838938
4 pin connector | 10 | €0.86 | €8.58 |  | https://www.digikey.com/product-detail/en/B4B-XH-A(LF)(SN)/455-2249-ND/1651047/?itemSeq=302805122
Power LED 5mm | 2 | €5.99 | €11.98 |  | https://www.reichelt.de/de/en/shop/product/led_5_mm_wired_cold_white_8700_mcd_140_-190382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
12V transformer | 2 | €38.95 | €77.90 |  | https://www.digikey.com/en/products/detail/PDQ30-Q24-S12-D/102-3892-ND/6165425?itemSeq=302805124
Manta Precision Bit Set | 1 | €69.99 | €69.99 |  | https://www.ifixit.com/de-de/products/manta-driver-kit-112-bit-driver-kit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
M2 M3 M4 M5 Schrauben und Muttern Set 945 pcs | 2 | €13.97 | €27.94 |  | huruirui M2 M3 M4 M5 Schrauben und Muttern Set Unterlegscheiben Sortierter Satz 304 Edelstahl 945pcs Zylinderkopfschrauben Gewinde Maschine Schrauben Hex Bolzen Reparatur Werkzeuge : Amazon.de: Baumarkt (https://www.amazon.de/huruirui-Unterlegscheiben-Sortierter-Edelstahl-Zylinderkopfschrauben/dp/B0BPGPT2BF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)
M3 Brass Standoffs 240 pcs | 1 | €15.99 | €15.99 |  | Litorange 240 Pieces M3 Male Female Hex Brass Spacer Standoff Screw Nut Threaded Pillar PCB Motherboard Assortment Kit : Amazon.de: Baumarkt (https://www.amazon.de/Litorange-Sechskant-Abstandshalter-Motherboard-Sortiment/dp/B07TP27SDY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)
Tires | 2 | €24.95 | €49.90 | extras in case we need to change them | Traxxas Reifen auf Felge weiss, soft günstig online kaufen bei Monste, 24,95 € (https://www.monsterhopups.de/Traxxas-Reifen-auf-Felge-weiss-soft)
Solder | 3 | €3.99 | €11.97 |  | Lötzinn 0.6mm, Lötzinn mit Flussmittel, Solder Wire 20g Lötzinn Bleifreier für Solder die Reparatur und den Heimwerker von Elektronischen Elektrischen Lötkomponenten : Amazon.de: Baumarkt (https://www.amazon.de/L%C3%B6tzinn-0-6mm-Elektronischen-Elektrischen-L%C3%B6tkomponenten/dp/B0CW9WLH82)
KabelBlinder | 1 | €5.00 | €5.00 | Local Shop, fast and cheaper | Woolworth
electric screw driver | 1 | €70.00 | €70.00 | electric | https://amzn.eu/d/90HDYud
SUM |  | €8532.28

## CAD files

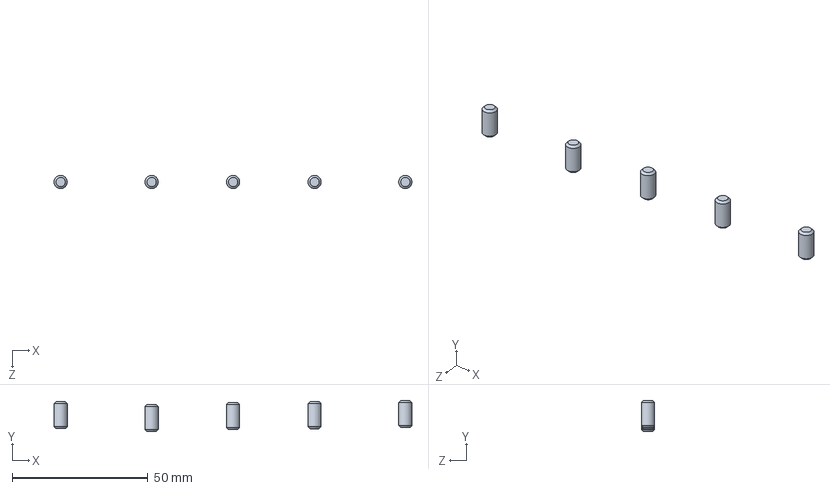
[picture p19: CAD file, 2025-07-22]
Components3DModelling/PlatformDeck/AssembledPlatform.SLDASM
131.8 x 11.4 x 4.90 mm
thePeg x 5

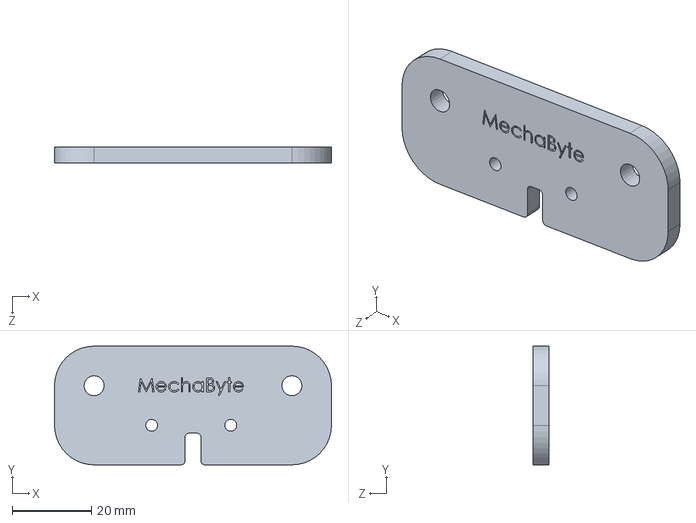
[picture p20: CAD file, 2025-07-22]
Components3DModelling/AntennaMount/AntennaMount.SLDPRT
70.0 x 30.0 x 4.00 mm

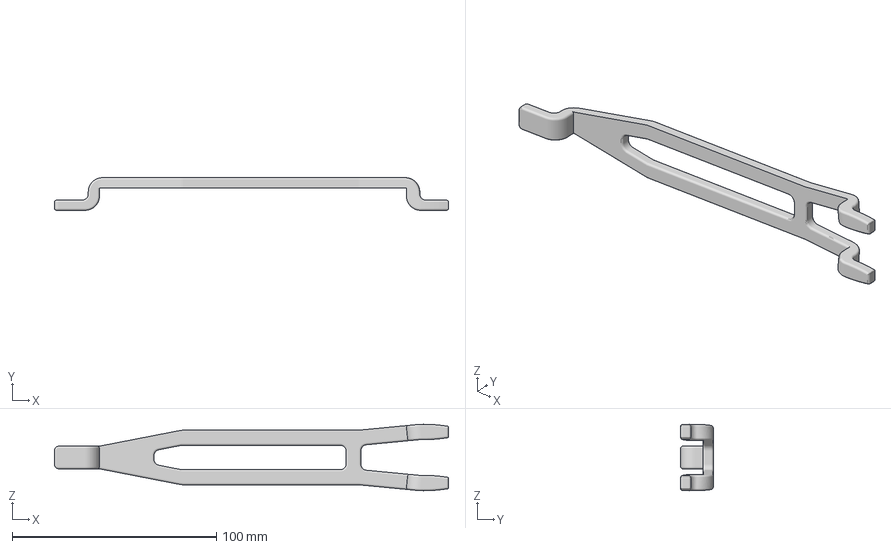
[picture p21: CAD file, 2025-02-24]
Components3DModelling/Battery Holder/Traxxas 4x4 LCG XL battery hold down.3mf
192.8 x 16.0 x 32.5 mm

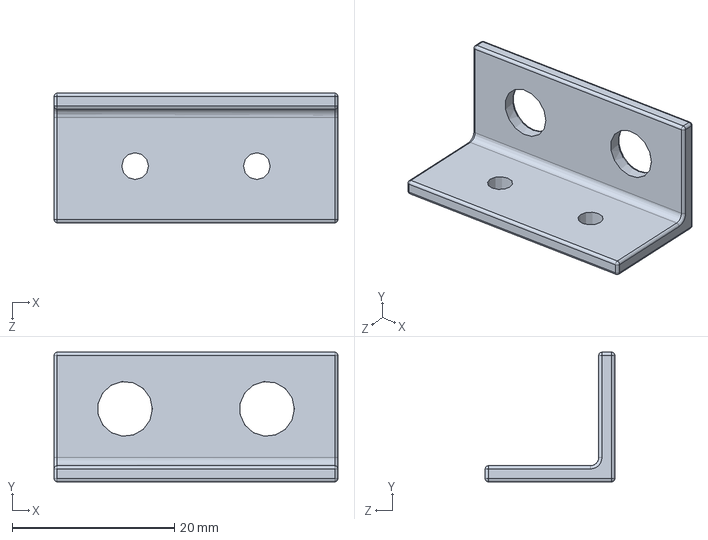
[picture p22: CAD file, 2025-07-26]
Components3DModelling/F1T_Platform_Deck_V3/antenna_mount/antenna_mount.SLDPRT
35.0 x 16.0 x 16.0 mm

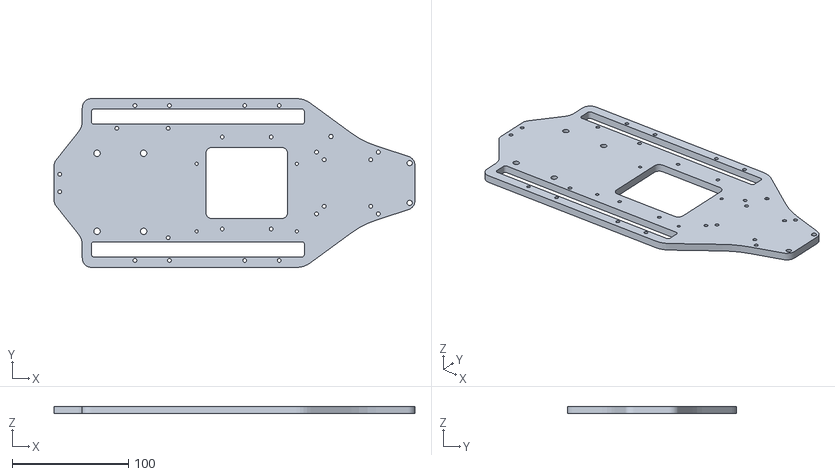
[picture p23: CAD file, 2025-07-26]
Components3DModelling/F1T_Platform_Deck_V3/Platform_Deck_V3.1 (New Powerboard)/Platform_Deck_V3.STL
310.0 x 145.0 x 6.35

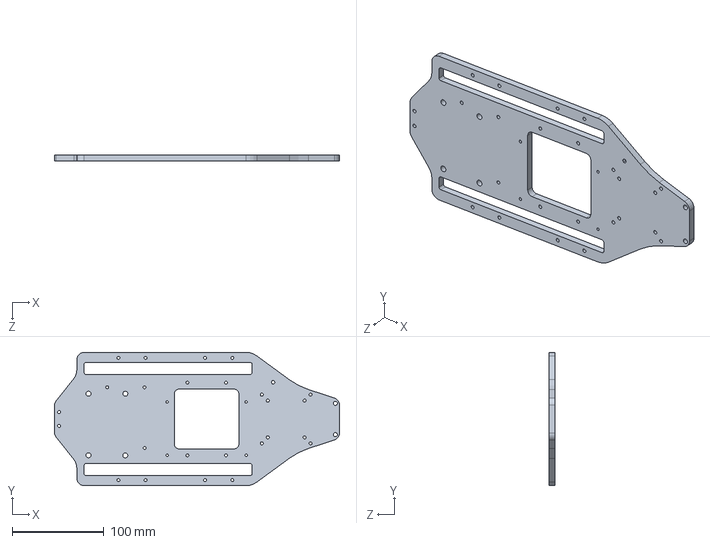
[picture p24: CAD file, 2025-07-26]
Components3DModelling/F1T_Platform_Deck_V3/Platform_Deck_V3.SLDPRT
310.0 x 145.0 x 6.35 mm

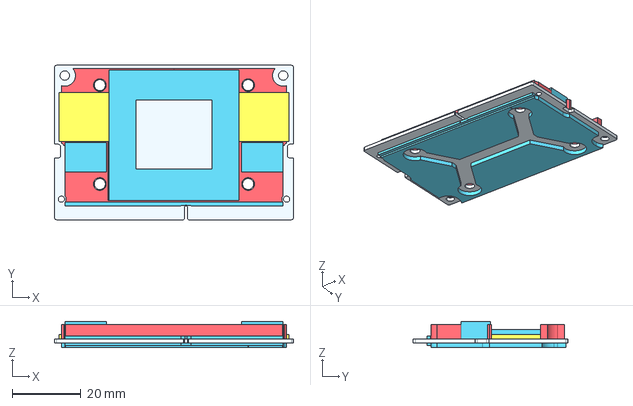
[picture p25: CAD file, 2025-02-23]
Components3DModelling/Jetson/Jetson_Orin_NX_Orin_Nano_Module_3D_STEP_Model_20230310/P3767-pcba-envelop_20230310.stp
69.6 x 45.0 x 7.68 mm

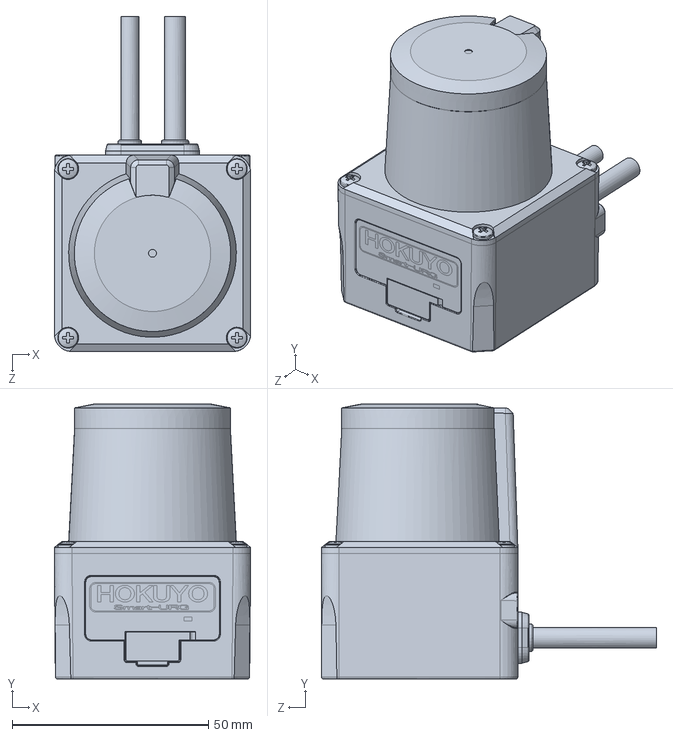
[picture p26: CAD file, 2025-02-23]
Components3DModelling/Lidar/ust-10_20lx.SLDPRT
50.0 x 70.0 x 85.3 mm

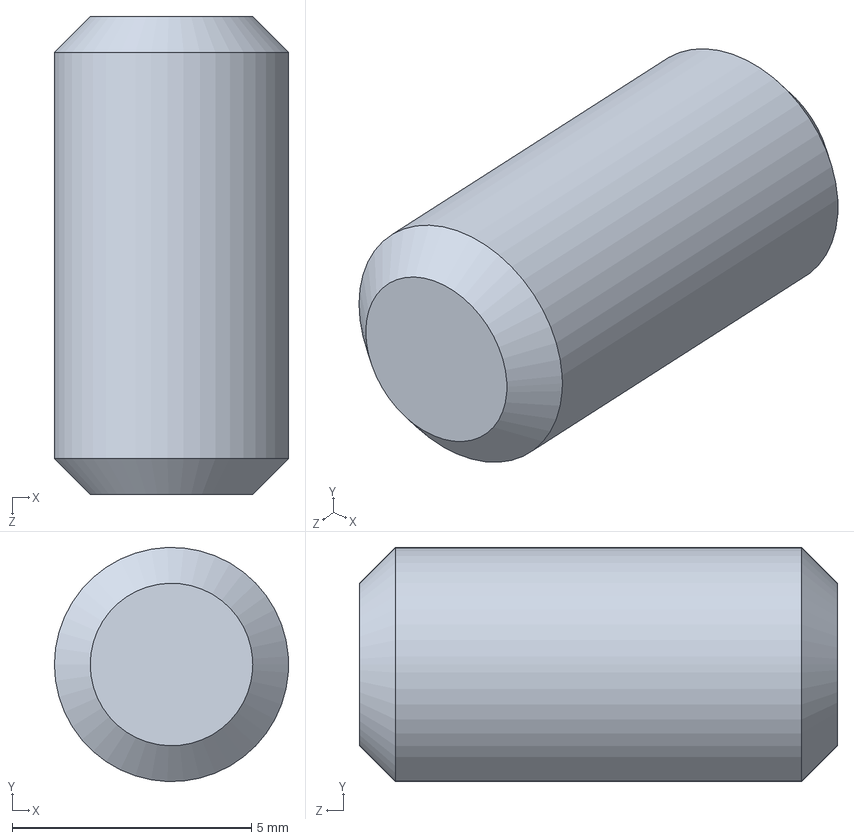
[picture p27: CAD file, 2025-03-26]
Components3DModelling/PlatformDeck/PlatformCadFiles/thePeg.SLDPRT
4.90 x 4.90 x 10.0 mm

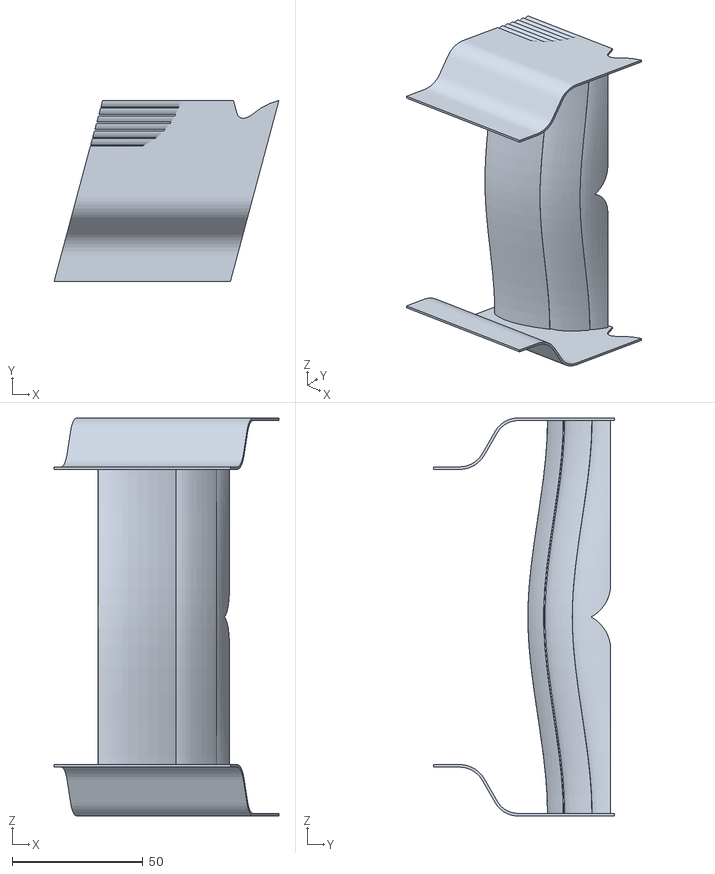
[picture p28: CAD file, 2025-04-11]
Components3DModelling/RearWing/rear_wing.STL
85.9 x 69.2 x 152.0

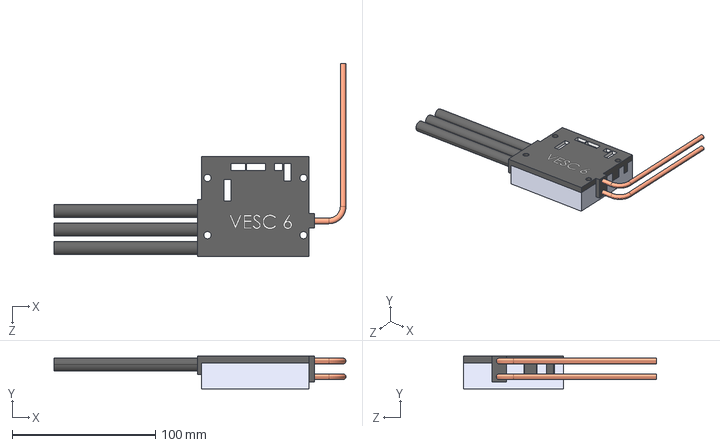
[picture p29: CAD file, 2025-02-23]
Components3DModelling/Vesc/vesc-6-heat-sink-1.snapshot.1/VESC_6_Assm.STEP
203.8 x 23.0 x 135.0 mm
VESC6HeatSink
VESC6Top

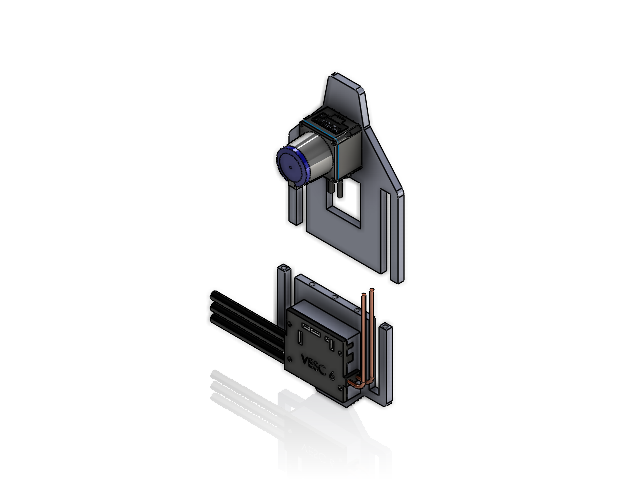
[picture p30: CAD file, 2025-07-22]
Components3DModelling/PlatformDeck/FullAssemblyAttempt.SLDASM
PF_Part1
PF_Part2
ust-10_20lx
VESC6HeatSink_2.STEP
VESC6Top_2.STEP

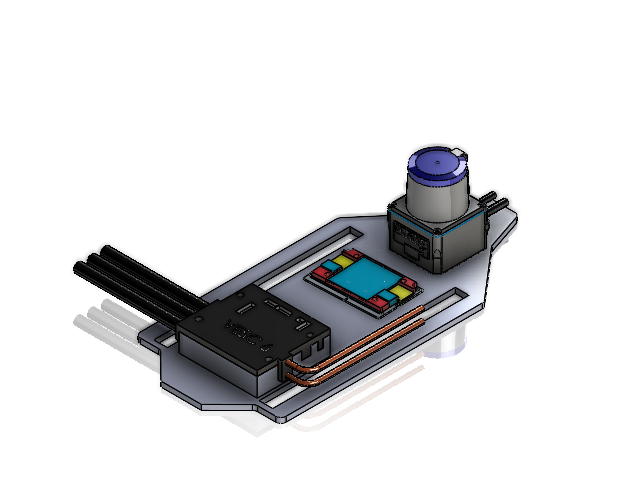
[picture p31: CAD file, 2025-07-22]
Components3DModelling/PlatformDeck/FullAsssemblyAttachedComponents.SLDASM
PlatformCM2
p3767-pcba-envelop_20230310
ust-10_20lx
VESC6HeatSink.STEP
VESC6Top.STEP

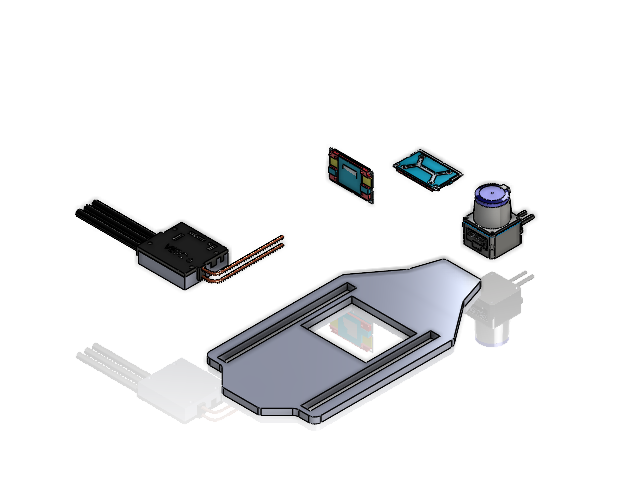
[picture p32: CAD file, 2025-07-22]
Components3DModelling/PlatformDeck/FullAssemblyDetachedComponents.SLDASM
PlatformCM
ust-10_20lx
VESC6HeatSink.STEP
VESC6Top.STEP
p3767-pcba-envelop_20230310 x 2

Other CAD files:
Components3DModelling/F1T_Platform_Deck_V3/Platform_Deck_V3.1 (New Powerboard)/Adaptor/Adaptor Drawing.dwg
Components3DModelling/F1T_Platform_Deck_V3/realsense_mount/realsense_mounting_plate.STEP
Components3DModelling/Traxxas Car/TraxxasCarModel/Chassis.SLDPRT
Components3DModelling/F1T_Platform_Deck_V3/agx_adaptor.SLDPRT
Components3DModelling/AntennaMount/AntennaMount.STL
Components3DModelling/F1T_Platform_Deck_V3/Platform_Deck_V3.1 (New Powerboard)/Adaptor/Livox_360_Adapter.dxf
Components3DModelling/F1T_Platform_Deck_V3/Platform_Deck_V3.1 (New Powerboard)/Adaptor/Powerboard Adaptor.dwg
Components3DModelling/F1T_Platform_Deck_V3/Platform_Deck_V3.1 (New Powerboard)/Adaptor/Powerboard Adaptor.dxf
Components3DModelling/F1T_Platform_Deck_V3/Platform_Deck_V3.1 (New Powerboard)/Adaptor/Powerboard Adaptor.sldprt
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

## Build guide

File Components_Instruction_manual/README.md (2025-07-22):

# Components Instruction Manual

## Overview
This folder contains assembly guides, user manuals, datasheets, and technical specifications for sensors, actuators, controllers, and other hardware components of the F1TENTH platform.

## Folder Structure

- Subfolders for Jetson, Lidar, VESC, and other components, each containing relevant manuals and datasheets.

## Getting Started

1. Browse subfolders for the component you need information about.
2. Refer to PDFs and HTML files for assembly, usage, and troubleshooting instructions.

## Contributions

Contributions are welcome! By contributing, you agree that your submissions will be licensed under the terms of the MIT License. Please submit improvements, corrections, or new documentation via pull request or open an issue. All contributions should include clear documentation and follow standard open-source practices.

---
For questions or support, refer to the files in this folder or contact the maintainers.
Author : Mohammed Abdelazim (mohammed@azab.io)
Maintainer : Yousuf Aboeldahab (yousuf.moh.dahab@outlook.com)

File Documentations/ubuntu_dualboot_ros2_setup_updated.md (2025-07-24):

# Dual Booting Ubuntu 22.04 with Windows 10/11 & Installing ROS 2 Humble

This guide will walk you through:

1. Setting up a bootable USB to install Ubuntu 22.04 (Jammy Jellyfish)
2. Dual booting Ubuntu with Windows
3. Initial Ubuntu setup
4. Installing ROS 2 Humble Hawksbill on Ubuntu

---

## Step 1: Download Ubuntu 22.04 Desktop Image and BalenaEtcher

- **Ubuntu 22.04 ISO** (Desktop version):  
   [Download here](https://releases.ubuntu.com/jammy/)

- **Balena Etcher** (USB boot tool):  
   [Download here](https://etcher.balena.io/)

---

## Step 2: Create a Bootable USB Stick

1. Insert a **blank USB stick (8GB or more)** into your PC. **Note**: All data on it will be erased.
2. Open **Balena Etcher**:
   - **Flash from file** → Select the Ubuntu ISO you downloaded.
   - **Select target** → Automatically selected if one USB is connected. If more than one device is plugged in, select your USB manually.
   - **Click "Flash"** → Wait until the process completes.
3. Once done, **eject the USB safely**.

---

## Step 3: Prepare Windows for Dual Boot

### 3.1 Backup Your Important Data
Before modifying partitions or OS setups, **back up all important files** from your Windows system.

### 3.2 Shrink Your Windows Partition
1. Open **Disk Management**:
   - Press `Win + S` → Search for **"Create and format hard disk partitions"**.
2. Right-click the main Windows partition (usually `C:`) → **Shrink Volume**.
3. Enter the amount to shrink in **MB** (e.g., 50000 MB for 50GB).
4. Click **Shrink**. You'll see **"Unallocated space"** – this is where Ubuntu will be installed.

**⚠️ Important:**  
Do **not** touch:
- `EFI System Partition`
- `Recovery Partition`

---

## Step 4: Boot Into Ubuntu Installation

### 4.1 Enable USB Boot (if not already enabled)
- Restart the PC → Press `F2`, `DEL`, or `ESC` to access the BIOS/UEFI.
- Under **Boot Options**:
  - Enable **USB boot**.
  - Set USB as **first boot device**.
  - **Disable Secure Boot** (Recommended for smoother Ubuntu installs).

### 4.2 Boot from USB
1. Restart your PC.
2. Go to **Settings > System > Recovery > Advanced startup > Restart now**.
3. Choose **Use a device** → Select the USB.
4. A black screen with GRUB will appear → Choose **"Try or Install Ubuntu"**.

---

## Step 5: Install Ubuntu Alongside Windows

1. Choose your language.
2. Select **"Install Ubuntu"**.
3. Choose your **keyboard layout** (usually English – US, usually: qwerty).
4. For **Installation Type**:
   - Choose **Normal Installation**
   - Check:
     - ✅ "Download updates while installing Ubuntu"

5. Connect to **Wi-Fi** and click **Continue**.

### 5.1 Manual Partitioning ("Something Else")
1. From the partition table:
   - Find the **"free space"** you created earlier (be careful not to use the wrong one).
2. Click on the free space → **Add**:
   - Type: **Primary**
   - Location: **Beginning of this space**
   - Use as: **Ext4 journaling file system**
   - Mount point: `/`
3. Click OK.

### 5.2 Set Boot Loader Location
- Below the partition list, choose:
  - **Device for boot loader installation**: Select the entry labeled **Windows Boot Manager** (usually `/dev/sda1`).

6. Click **Install Now** → Confirm changes → Continue.

---

## Step 6: Finalize Installation

1. Choose your **timezone**.
2. Set:
   - Your **Name**
   - Your **Computer Name**
   - Your **Username**
   - Your **Password** (used for login and sudo commands)

3. Click **Continue** → Installation starts. It can take ~30–60 minutes.

---

## Step 7: Reboot & Access Ubuntu

1. Once installation completes, click **Restart Now**.
2. When prompted, **remove the USB stick** and press **Enter**.
3. On every startup, you’ll now see the **GRUB menu** to choose between:
   - Ubuntu
   - Windows Boot Manager

---

## Step 8: Post-Installation Checks

- Boot into both **Windows and Ubuntu** to confirm dual boot works.
- **Update Ubuntu**:
  ```bash
  sudo apt update && sudo apt upgrade
  ```

---

## Step 9: Install ROS 2 Humble on Ubuntu 22.04

## 9.1 System Setup

### Set Locale

Ensure your locale supports UTF-8. If you're using a minimal environment (like Docker), the default locale might be POSIX. To configure a UTF-8 compatible locale:

```bash
locale  # check current locale

sudo apt update && sudo apt install locales
sudo locale-gen en_US en_US.UTF-8
sudo update-locale LC_ALL=en_US.UTF-8 LANG=en_US.UTF-8
export LANG=en_US.UTF-8

locale  # verify settings
```

---

## 9.2 Add the ROS 2 APT Repository

### 9.2.1 Enable Ubuntu Universe Repository:

```bash
sudo apt install software-properties-common
sudo add-apt-repository universe
```

### 9.2.2 Add ROS 2 apt source:

Install the latest ROS 2 source package:

```bash
sudo apt update && sudo apt install curl -y
export ROS_APT_SOURCE_VERSION=$(curl -s https://api.github.com/repos/ros-infrastructure/ros-apt-source/releases/latest | grep -F "tag_name" | awk -F\" '{print $4}')
curl -L -o /tmp/ros2-apt-source.deb "https://github.com/ros-infrastructure/ros-apt-source/releases/download/${ROS_APT_SOURCE_VERSION}/ros2-apt-source_${ROS_APT_SOURCE_VERSION}.$(. /etc/os-release && echo $VERSION_CODENAME)_all.deb"
sudo dpkg -i /tmp/ros2-apt-source.deb
```

---

## 9.3 Install Development Tools & ROS Tools

Install common development packages:

```bash
sudo apt update && sudo apt install -y \
  python3-flake8-docstrings \
  python3-pip \
  python3-pytest-cov \
  ros-dev-tools
```

Install additional tools for Ubuntu 22.04:

```bash
sudo apt install -y \
  python3-flake8-blind-except \
  python3-flake8-builtins \
  python3-flake8-class-newline \
  python3-flake8-comprehensions \
  python3-flake8-deprecated \
  python3-flake8-import-order \
  python3-flake8-quotes \
  python3-pytest-repeat \
  python3-pytest-rerunfailures
```

---

## 9.4 Get ROS 2 Code

Create a workspace and clone the source code:

```bash
mkdir -p ~/ros2_humble/src
cd ~/ros2_humble
vcs import --input https://raw.githubusercontent.com/ros2/ros2/humble/ros2.repos src
```

---

## 9.5 Install Dependencies using `rosdep`

Ensure your system is updated, then install dependencies:

```bash
sudo apt upgrade
sudo rosdep init
rosdep update
rosdep install --from-paths src --ignore-src -y --skip-keys "fastcdr rti-connext-dds-6.0.1 urdfdom_headers"
```

>  If you're using a derivative like Linux Mint, and get an error such as `Unsupported OS [mint]`, append:
> ```bash
> --os=ubuntu:jammy
> ```

---

## 9.6 Optional: Install Additional DDS Implementations

If you'd like to use DDS or RTPS vendors other than the default, refer to:

[DDS Vendor Installation Guide](https://docs.ros.org/en/humble/Installation/Alternatives/DDS-Implementations.html)

## Official ROS 2 Humble Installation Guide

For more details, visit the official ROS 2 documentation:  
[https://docs.ros.org/en/humble/Installation.html](https://docs.ros.org/en/humble/Installation.html)
 
---

## Optional Troubleshooting: GRUB Menu Not Showing

Sometimes after Ubuntu installation, the system might boot straight into Windows, skipping the GRUB menu. To fix this:

### Step 1: Make GRUB the Default Bootloader
Boot into **Ubuntu** (you might need to use the Boot Menu key like `F12` or `ESC` during startup).

Open a terminal and run:
```bash
sudo grub-install
sudo update-grub
```

This ensures GRUB is properly installed and configured.

---

### Step 2: Change UEFI Boot Order to Boot Ubuntu First
1. Reboot your computer and enter the BIOS/UEFI settings (`F2`, `DEL`, `ESC`, or as per your device).
2. Look for **Boot Order** or **Boot Priority** settings.
3. Move **Ubuntu** or `grubx64.efi` (usually under `/EFI/ubuntu/`) **above** the Windows Boot Manager.
4. Save and exit.

This ensures GRUB loads before Windows Boot Manager.

---

### Step 3: If Windows Keeps Overriding GRUB
From **Windows**, open **Command Prompt as Administrator** and run:
```cmd
bcdedit /set {bootmgr} path \EFI\ubuntu\grubx64.efi
```

This tells the Windows Boot Manager to defer to GRUB.

---

### Step 4: Add Windows Entry to GRUB (If Missing)
Back in Ubuntu, run:
```bash
sudo os-prober
sudo update-grub
```

This scans for Windows and adds it to the GRUB boot menu.

---

### ✅ Final Result:
On reboot, you should now see a menu like:
```
Ubuntu
Advanced options for Ubuntu
Windows Boot Manager (on /dev/nvme0n1p1)
```

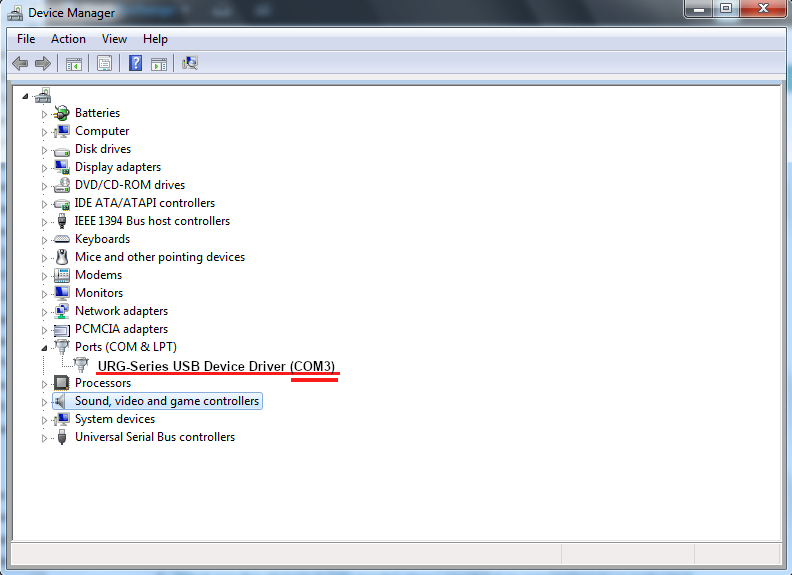
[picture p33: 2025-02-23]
Components_Instruction_manual/Lidar/Connect a USB type LiDAR to your PC _ Scanning Range Finder _ How to Use _ HOKUYO AUTOMATIC CO., LTD._files/20230418151214_359.png

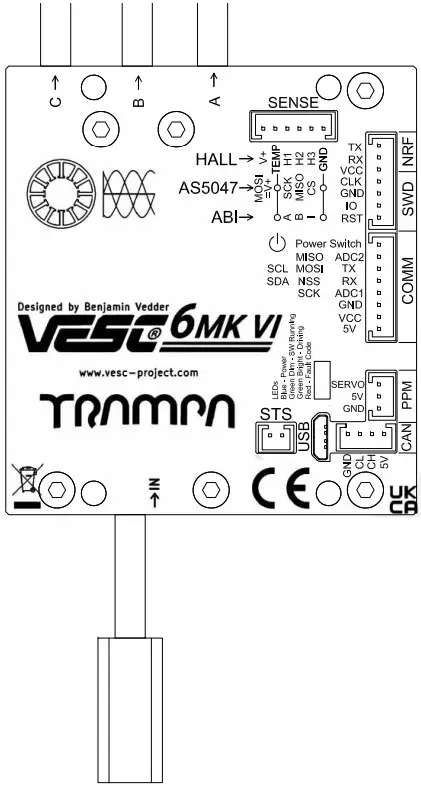
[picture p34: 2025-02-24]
Components_Instruction_manual/VESC/TRAMPA-VESC-6-MK-VI-Vedder-ESC-For-DC-And-BLDC-Motors-Connectors-and-Switchs.webp

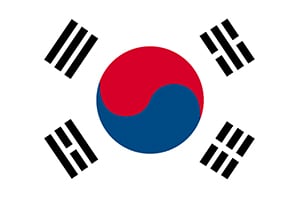
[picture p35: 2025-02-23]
Components_Instruction_manual/Lidar/Connect a USB type LiDAR to your PC _ Scanning Range Finder _ How to Use _ HOKUYO AUTOMATIC CO., LTD._files/flag_kr.jpg

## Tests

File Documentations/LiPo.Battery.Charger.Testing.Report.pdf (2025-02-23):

# LiPo Battery & Charger Testing Report

Reported by:

Mohammed Azab
Nada Mahomud

Date: 05. Feb. 2025
Version: 1.0

Table of Contents

1. Introduction
2. Equipment & Components
3. Testing Procedure
- Battery Inspection
- Charging Process
- Load Testing
- Connection to Car
4. Test Results & Observations
5. Safety Guidelines & Best Practices
6. Conclusion & Recommendations

### 1. Introduction

Objective

This document outlines the testing procedures for a LiPo battery and charger to verify their functionality and ensure compatibility with the target vehicle. It also addresses connection differences and possible solutions.

Scope

- Checking battery health and charging performance.
- Measuring battery behavior under load conditions.
- Ensuring compatibility with the vehicle's power system.

### 2. Equipment & Components

Component | Model/Specification | Description
Battery | Zeee 7200mAh LiPo | LiPo, 7.4V 7200mAh
Charger | iMax B6 80W LiPo Balance Charger | Supports LiPo, 80W

### 3. Testing Procedure

### 3.1 Battery Inspection

- Checked for physical damage (swelling, leakage, broken connectors). Observation: No physical damage detected.
- Measured battery voltage before charging.

### 3.2 Charging Process

1. Connected the charger to a power source.
2. Set charging parameters (battery type, voltage, current).
3. Connected the battery and initiated charging.
4. Monitored the charging process (temperature, charge time).
5. Verified that the battery reached full charge without issues.

### 3.3 Load Testing

- Discharged the battery under controlled conditions.
- Measured voltage drop and current draw.
- Ensured the battery maintained stable output within safe limits.

### 3.4 Connection to Car

- Attempted to connect the battery to the vehicle.
- Observation: The battery connector differs from the car body connector, requiring a replacement connector.

### 4. Test Results & Observations

- Charging time and efficiency were satisfactory.
- Battery performed well under load.

- No malfunctions or critical issues were observed.
- The main issue encountered was the incompatibility of the battery connector with the car body, necessitating a new connector for proper integration.

### 5. Safety Guidelines & Best Practices

- Always charge in a fireproof area.
- Do not overcharge or discharge below safe limits.
- Ensure proper polarity and secure connections.
- Store batteries at recommended voltage levels when not in use.

### 6. Conclusion & Recommendations

- The battery and charger performed as expected with no faults.
- The main issue identified was the mismatch between the battery and car body connectors.
- Recommendation: Purchase and replace the connector to ensure compatibility.
- Consider future upgrades or alternative battery models with pre-matching connectors to avoid similar issues.

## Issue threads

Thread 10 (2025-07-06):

Document hardware changes

FamALouiz, 2025-07-06:
📝 Description

Document the hardware setup used in the previous F1TENTH competition, and clearly outline the planned hardware architecture for the new car. This includes:

    Listing all components previously used (sensors, compute units, actuators, power systems, etc.)

    Specifying changes or upgrades in the new car’s hardware

    Creating a comprehensive Bill of Materials (BOM) for both setups

    Adding the BOM and hardware documentation (diagrams, specifications, part numbers, etc.) to the hardware repository

This documentation will serve as a reference for current development and future team members, ensuring transparency, traceability, and easier debugging or replacement.

Mohammed-Azab, 2025-07-19:
@nada28591, Don't forget to add the BOM file to the Hardware Repo, and also check with @yousufAboeldahab157 the name convention and where to put it in the Repo.

Closed 2025-07-19.

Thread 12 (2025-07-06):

Design/Print Request: F1TENTH Custom PCB (Powerboard)

Mohammed-Azab, 2025-07-06:
### 📄 Description:
We require the design files to be reviewed and used to manufacture and assemble the **F1TENTH Powerboard v1.0**, as specified in the official GitHub repository:
🔗 https://github.com/f1tenth/f1tenth_powerboard_v10

This PCB handles power distribution for ESCs, sensors, compute units, and other components in the F1TENTH car.

---

### 📦 Scope of Work:
- Review existing **KiCad project**, schematics, and BOM.
- Generate **Gerber and fabrication files**.
- Source and manufacture PCB via a reputable manufacturer.
- Assemble the PCB using components from the provided BOM.
- Optional: Perform continuity and voltage testing post-assembly.

---

### Outcomes:
- ✅ Fabricated and assembled power board.
- ✅ All ports in PCB must be functional.
- ✅ All manufacturing files (Gerbers, drill files, pick-and-place, etc.)
- ✅ Photos or short video of the assembled board

---

### ✅ Acceptance Criteria:
- PCB must be true to the original design unless reviewed and approved.
- Assembled board must power up and pass basic functionality tests.
- Final board must be mountable within the F1TENTH chassis.
- All source and output files must be delivered with documentation.

FamALouiz, 2025-07-18:
Parts have been sent for printing
@YousefSayed2004 Can you add the link to track it (if applicable)

YousefSayed2004, 2025-07-18:
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

FamALouiz, 2025-08-02:
@YousefSayed2004 mentioned that they have arrived. Upon receiving them, please close the ticket.

Mohammed-Azab, 2025-08-22:
@YousefSayed2004 what is the status of the new PCBs? Did it arrive yet ? Regarding the required electronics components, did you finalize the list?

Mohammed-Azab, 2025-08-27:
To be honest, I don’t mind which electronics component provider we use, since we’ll need to test the components anyway to ensure they work. So feel free to go ahead and place the order.

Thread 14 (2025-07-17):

Refactor Hardware Repository for 2025 Release

Mohammed-Azab, 2025-07-17:
File Renaming:

-     Rename all files to follow a consistent and proper naming convention aligned with project standards.

-     Differentiate between legacy and new files by appending clear identifiers, e.g., roboracer2025_ prefix or suffix for new files.

Bill of Materials (BOM):

-     Add the latest BOM reflecting 2025 components.

-     Clearly separate or archive the old BOM files from the updated ones to avoid confusion.

README Update:

-     Review the README file for syntax, formatting, and clarity.

-     Update content to reflect current project status, instructions, and hardware details.

Documentation:

-     Add any missing technical documentation including wiring diagrams, assembly instructions, and hardware specs.

-     Ensure all documentation is up-to-date and consistent across the repo.

CAD Files:

-     Add all relevant CAD files to the repository.

-     Organize them in a dedicated directory with proper version control.

Additional Improvements (Optional but Recommended):

-     Add a CONTRIBUTING.md if not present, to guide contributors on repo standards.

-     Verify that all files have appropriate licenses and headers.

-     Run a repository lint or validation tool if available to enforce standards.

Mohammed-Azab, 2025-07-21:
I approved the pull request but there is a minor edit which needs to be done. It's a naming convention.

Mohammed-Azab, 2025-07-21:
pls, after making the last commit, merge the branches and then make a pull request from dev to the main branch

Closed 2025-07-22.

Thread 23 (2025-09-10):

Laser cut the platfom deck

Mohammed-Azab, 2025-09-10:
Laser cut the new official platform from Acrylic sheet 6mm
https://github.com/GIU-F1Tenth/hardware/tree/main/Components3DModelling/F1T_Platform_Deck_V3

Mohammed-Azab, 2025-09-14:
2 pieces Acrylic 6mm

Closed 2025-09-14.

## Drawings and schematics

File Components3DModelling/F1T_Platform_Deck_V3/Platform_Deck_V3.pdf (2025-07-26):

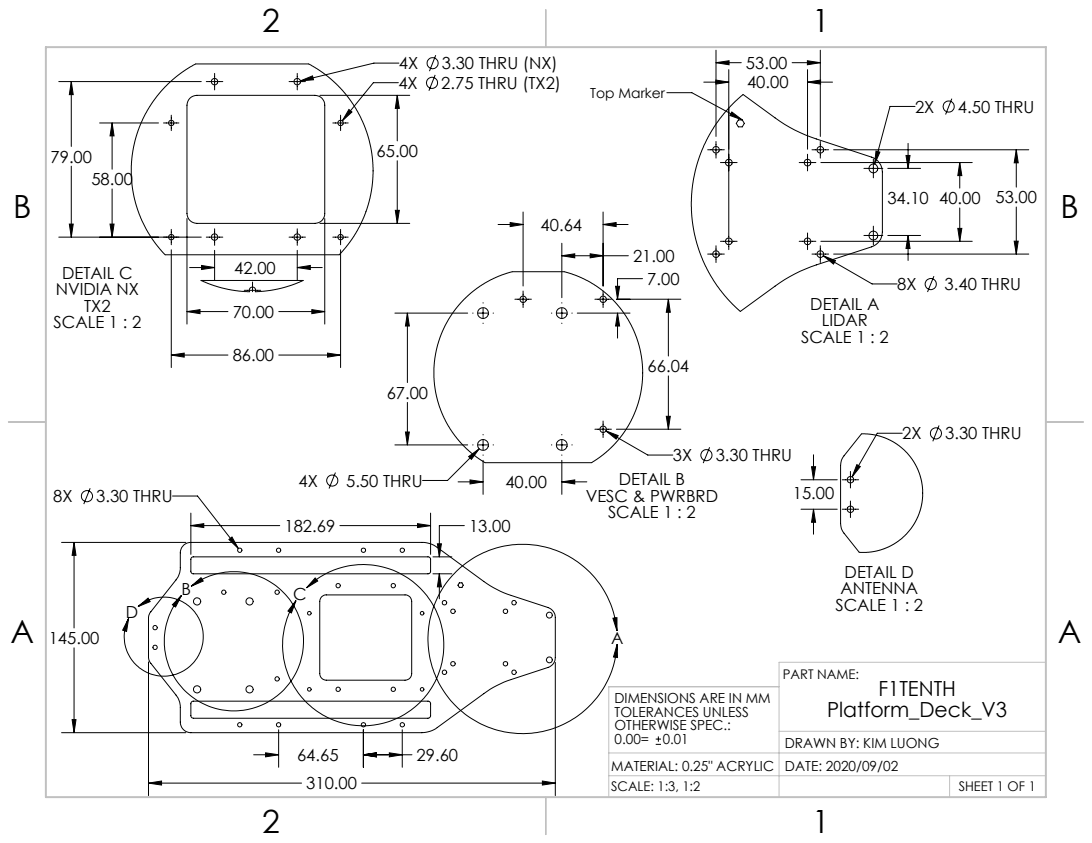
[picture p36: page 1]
8X 3.30 THRU; 2X 4.50 THRU; 3.40 THRU; DETAIL A SCALE 1 : 2; Top Marker; 5.50 THRU; 3X 3.30 THRU DETAIL B VESC & PWRBRD SCALE 1 : 2; 4X 2.75 THRU (TX2); 4X 3.30 THRU (NX); DETAIL C NVIDIA NX SCALE 1 : 2; 2X 3.30 THRU; DETAIL D SCALE 1 : 2; PART NAME:

DIMENSIONS ARE IN MM
TOLERANCES UNLESS
OTHERWISE SPEC.:

DRAWN BY: KIM LUONG

MATERIAL: 0.25" ACRYLIC | DATE: 2020/09/02
SCALE: 1:3, 1:2 | | SHEET 1 OF 1

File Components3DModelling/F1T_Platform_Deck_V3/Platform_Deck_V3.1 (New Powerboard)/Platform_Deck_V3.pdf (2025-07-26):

B B

2

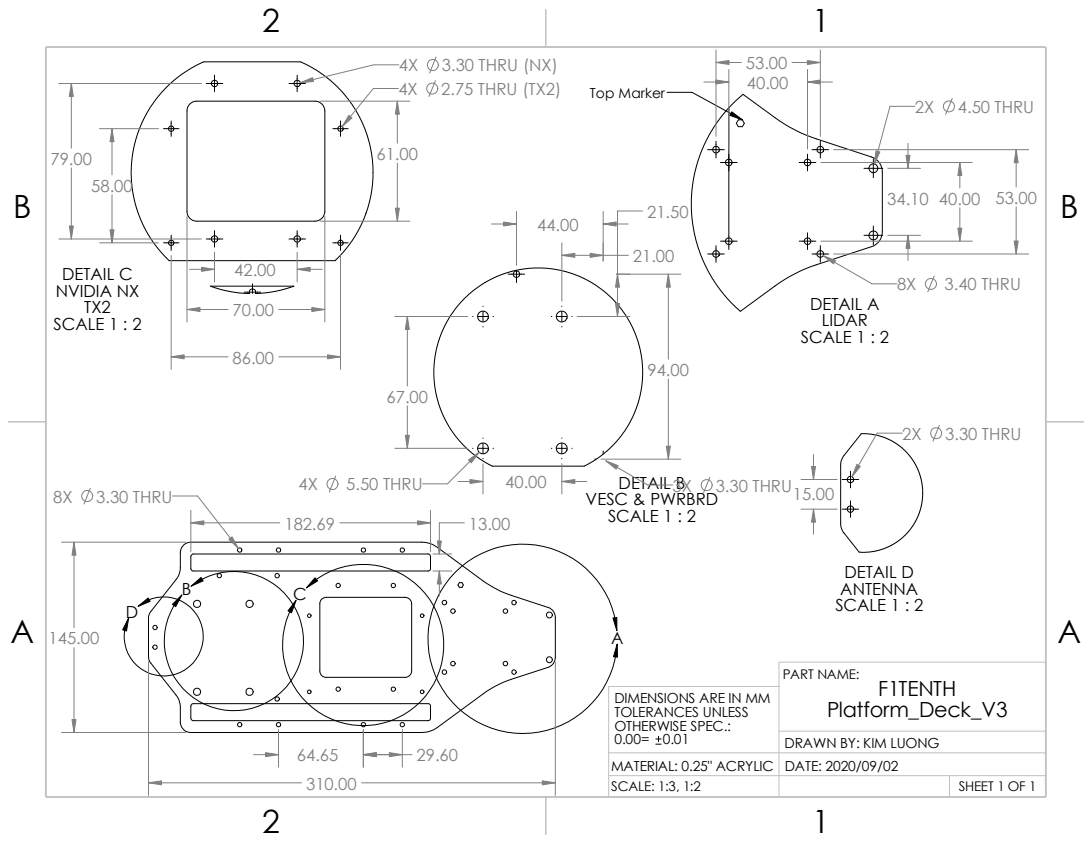
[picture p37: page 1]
Platform_Deck_V3; PART NAME:; DRAWN BY: KIM LUONG; LIDAR SCALE 1 : 2; DETAIL A; Top Marker; 2X 4.50 THRU; 3.40 THRU; DETAIL D ANTENNA SCALE 1 : 2; 2X 3.30 THRU; DETAIL B VESC & PWRBRD SCALE 1 : 2; 5.50 THRU; 3X 3.30 THRU; 8X 3.30 THRU; DETAIL C NVIDIA NX TX2 SCALE 1 : 2; 4X 2.75 THRU (TX2); 4X 3.30 THRU (NX)

F1TENTH DIMENSIONS ARE IN MM
TOLERANCES UNLESS
OTHERWISE SPEC.:

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

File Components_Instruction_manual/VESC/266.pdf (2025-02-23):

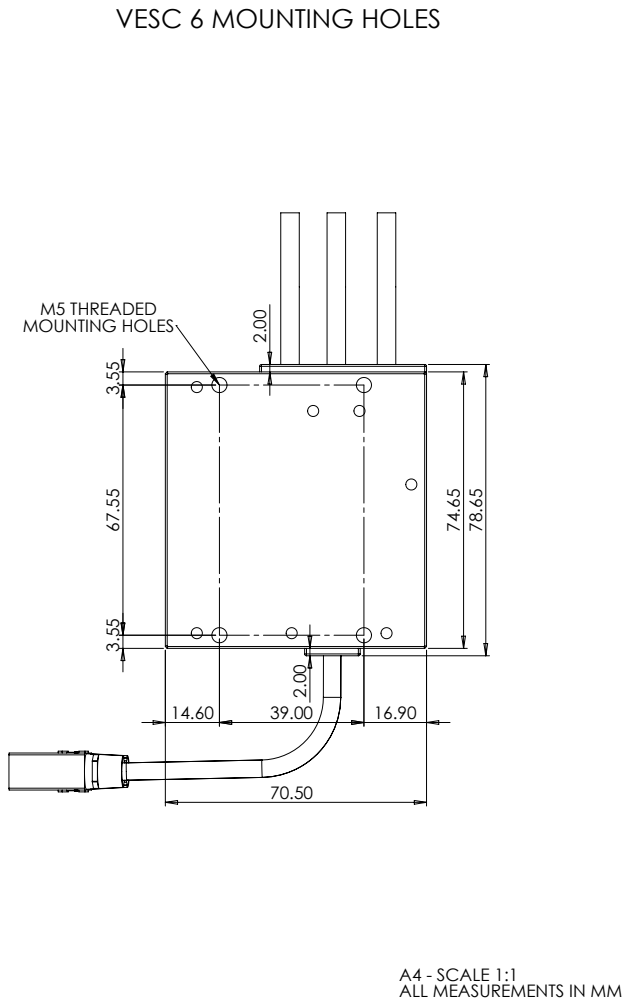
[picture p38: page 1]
M5 THREADED MOUNTING HOLES

VESC 6 MOUNTING HOLES

A4 - SCALE 1:1
ALL MEASUREMENTS IN MM

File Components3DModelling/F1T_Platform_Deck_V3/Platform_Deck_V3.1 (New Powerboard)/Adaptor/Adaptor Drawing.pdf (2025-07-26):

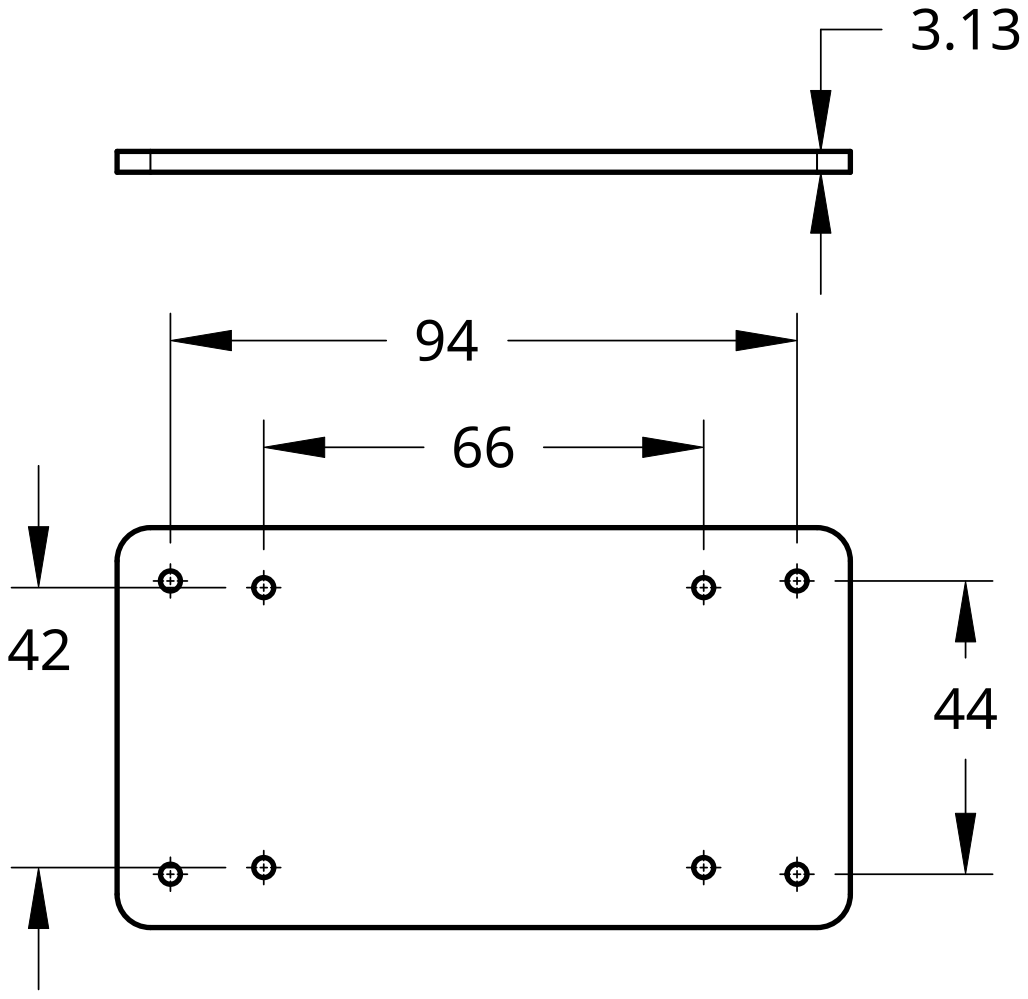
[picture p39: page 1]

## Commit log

2025-02-23 added BillsOfMatrerials
    [F1TenthBOM.xlsx]
2025-02-23 added Jetson 3D module
    [P3767-pcba-envelop_20230310.stp, p3767-pcba-envelop_20230310.SLDPRT]
2025-02-23 added Lidar 3D module
    [ust-10_20lx.SLDPRT]
2025-02-23 added Vesc 3D module
    [VESC_6_Assm.STEP]
2025-02-23 added Lidar instruction_manual
2025-02-23 added VESC instruction manual
2025-02-23 added Assembly Pictures
    for demonstration purpose
2025-02-24 added battery hold piece 3D module
    [Traxxas 4x4 LCG XL battery hold down.3mf]
2025-02-24 added Vesc photos
2025-02-24 added VESC documentation
2025-02-27 added Jetson-ubuntu installation manual
2025-03-26 added updated Platform CAD file
    increased the width, made the sluts rounded, added a housing for the lidar and made a holes for the VESC
    [PF_Part1.SLDPRT, PF_Part1.STL, PF_Part2.SLDPRT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]
2025-04-03 Changed Slot size
    [PF_Part1.SLDPRT, PF_Part1.STL]
2025-04-03 Made the path of the Beg longer
    [PF_Part1.SLDPRT, PF_Part1.STL]
2025-04-03 Made part2 align Part2
    [PF_Part2.SLDPRT, PF_Part2.STL]
2025-04-03 Edited the peg accordingly
    [thePeg.SLDPRT, thePeg.STL]
2025-04-03 Fixed Screw Path Problem
    [PF_Part1.SLDPRT, PF_Part1.STL]
2025-04-03 Added DXF file
    [PF (Current).DXF]
2025-04-04 Created 2 new parts with diff components order
    [Part1LVJ.SLDPRT, Part2LVJ.SLDPRT]
2025-04-04 Created STL File for the upper half
    [Part1LVJ.STL]
2025-04-11 Created Rear wing file 3D
    [rear_wing.STL]
2025-04-11 Added outlined sketched
    [Assem1.SLDASM, Part2LVJ.STL]
2025-06-15 Modified 3d part to take the camera into consideration
    [P1Final_withCamera.STL]
2025-06-16 Edited the Part2 pegs slots
    [P2Final_withCamera.STL]
2025-06-16 Added The UNI Name
    [P1Final1_withCamera.STL]
2025-06-16 added the file with engraving on it
    [P1Final1_withCamera.STL]
2025-07-18 Put Assem1 in correct place
    [Assem1.SLDASM]
2025-07-18 refactor/initial refactor of repo
    [Assem1.SLDASM, F1TenthBOM2025.xlsx, P1Final1_withCamera.STL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]
2025-07-19 Add: All the local CAD files
    [Assem.SLDASM, Assem1.SLDASM, AssemOfThePlatform.SLDASM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]
2025-07-19 Add the gcode file for the antenna_mount
    [AntennaMount.SLDPRT, AntennaMount.STL]
2025-07-19 Add files via upload
    This is the Roboracer 2026 BOM with all the hardware requirements for both cars that should be ordered.
    [Roboracer2026BOM.xlsx]
2025-07-19 Put 2026 BOM file in correct place
    [Roboracer2026BOM.xlsx]
2025-07-20 create antenna mount folder
    [AntennaMount.SLDPRT, AntennaMount.STL]
2025-07-20 Changed file names to follow naming standard and make the files understandable
    [AntennaMount.SLDPRT, AntennaMount.STL, AssembledPlatform.SLDASM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]
2025-07-20 Moved AntennaMount and Platform_Deck files to the correct folder and removed duplicate files
    [AntennaMount.SLDPRT, AntennaMount.STL, Assem1.SLDASM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]
2025-07-20 Changed folder name from Platform_deck to PlatformDeck
    [AssembledPlatform.SLDASM, FullAssemblyAttempt.SLDASM, FullAssemblyDetachedComponents.SLDASM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]
2025-07-20 Fixed General README File, Added README Files in Components3DModelling and PlatformDeck folders, Fixed 2025 BOM
    [F1TenthBOM2025.xlsx]
2025-07-22 Changed naming convention for TraxxasCar Directory
    [Chassis.SLDPRT, Chassis.STL]
2025-07-24 Add F1tenth official platform deck files
    [Adaptor Drawing.dwg, Livox_360_Adapter.dxf, Platform_Deck_V3.DWG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]
